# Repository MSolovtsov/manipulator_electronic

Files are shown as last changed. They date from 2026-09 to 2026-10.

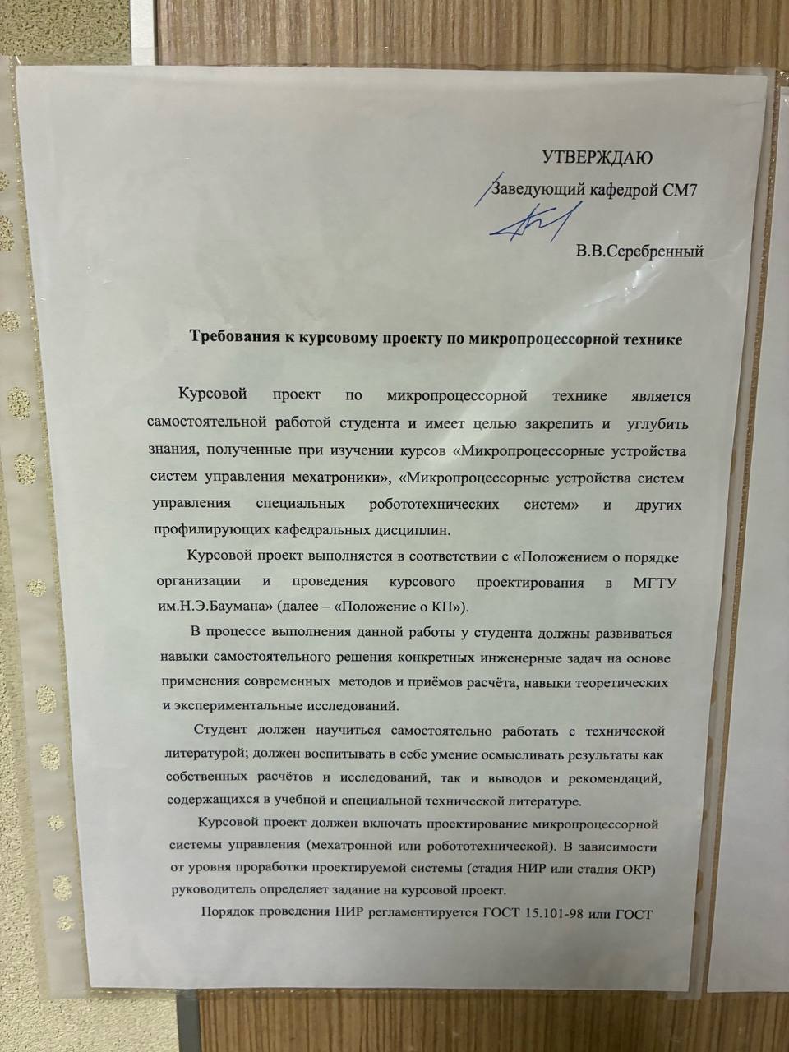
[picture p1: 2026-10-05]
docs/kp-requirements/kp-requirements-1.jpg

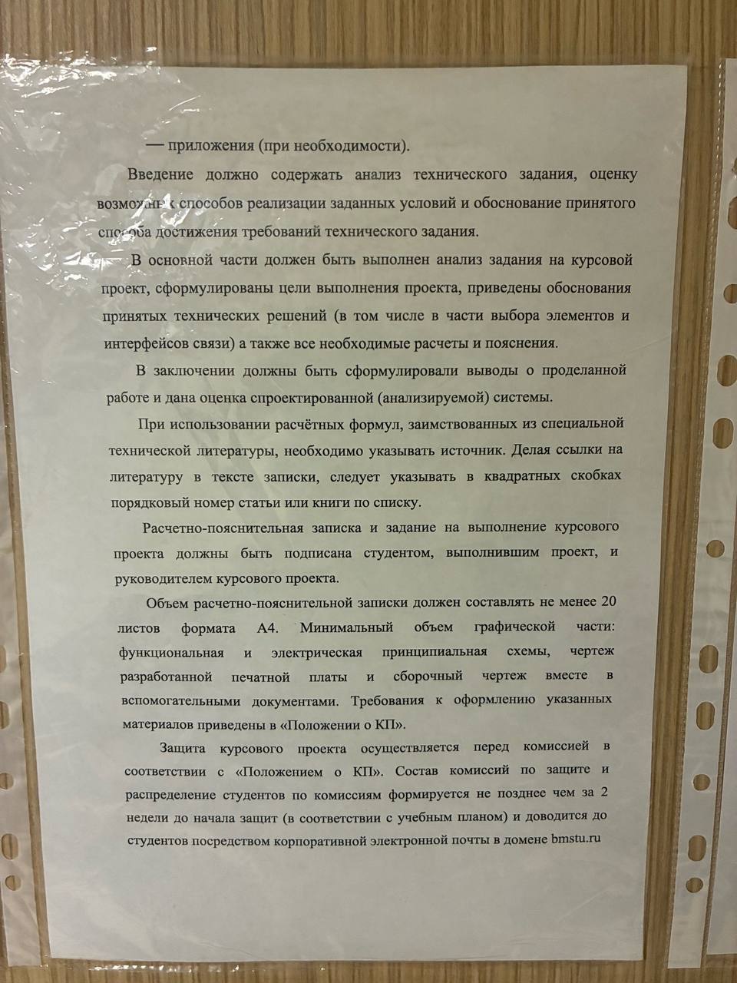
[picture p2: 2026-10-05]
docs/kp-requirements/kp-requirements-3.jpg

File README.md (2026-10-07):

# Электроника манипулятора для лабораторных работ

Подпроект «Электроника» проекта «Манипулятор для лабораторных работ». Подключён как Git submodule
к родительскому репозиторию `educational-manipulator`.

## Состав электроники

Архитектура: контроллер ESP32-S3 (связь с ПК по USB); четыре канала привода
M1…M4 в основании — коллекторные ДПТ 24 В с драйвером, реле отключения,
датчиком тока и I2C-энкодером через мультиплексор (M1 — поворот платформы,
M2…M4 — звенья через токосъёмное кольцо); съёмный схват M5 с собственной
электроникой по UART; два режима работы — полный (от ESP32) и лабораторный
(управление звеном с внешнего разъёма), переключаемые кнопкой KH; питание от
внешнего адаптера 24 В с гальванической развязкой логики от силовой части.

Конкретные компоненты, их статусы (утверждено / предложение / уточняется),
спорные пункты и цены — в базе компонентов **`bom/Component_Base.xlsx`**
(листы «Компоненты», «Модули», «Отклонено», «Сводка», «Справочники»).
Текстовые копии листов для просмотра диффов — `bom/csv/`, обновляются
скриптом `scripts/export_component_base.py`.

Не определены: число степеней свободы, грузоподъёмность, двигатели, состав и
число плат. Исходные данные — концепт на доске Miro.

| Плата | Назначение | Кол-во | Текущая ревизия |
|---|---|---|---|
| CH | Плата силовой части: развязка, драйвер, реле отключения, датчик тока, реле режима | 4 | — |
| MC | Плата микроконтроллера: ESP32-S3, мультиплексор I2C, оптореле KH, концевик M1, UART схвата, разъёмы CH | 1 | — |
| PS | Плата питания: реле шины 24 В, TVS, XL4015E, изолированный DC-DC острова, раздача +24 | 1 | — |
| LR | Плата режима ЛР: клеммы M1…M4, защита, PCF8574 и индикаторы звеньев | 1 | — |
| GR | Электроника схвата (по ТЗ на схват) | 1 | — |

Обоснование разделения, состав и связи между платами —
`docs/board-partition.md`. Плата CH проектируется после выбора двигателя
(от него зависят драйвер и реле отключения); MC, PS и LR — не ждут.

## Структура репозитория

```
electronics/
├── lib/            общие библиотеки KiCad для всех плат
│   ├── symbols/    символы (*.kicad_sym)
│   ├── footprints/ посадочные места (*.pretty/)
│   └── 3dmodels/   3D-модели компонентов (*.step, *.wrl) — только используемые в проекте
├── boards/         KiCad-проекты; один каталог = одна плата
│   └── <плата>/
│       └── release/<rev>/   замороженные выходные файлы изготовленной ревизии
├── system/         уровень системы: структурная схема, распиновка разъёмов
│   └── wiring/     схема соединений между платами, жгуты, кабели
├── calc/           расчёты: питание, токи, тепловой режим
├── bom/            база компонентов Component_Base.xlsx + csv/ для диффов
├── docs/           обоснование выбора приводов, датчиков, контроллера
└── scripts/        скрипты экспорта и проверки (export_component_base.py)
```

В репозиторий попадают исходники KiCad (`*.kicad_pro`, `*.kicad_sch`, `*.kicad_pcb`),
таблицы библиотек проекта (`sym-lib-table`, `fp-lib-table`), содержимое `lib/` и
каталоги `release/`. Резервные копии, автосохранения, локальные настройки вида
и пересоздаваемые выходные файлы (Gerber, отчёты DRC/ERC) не хранятся — см. `.gitignore`.

## Инструменты

- KiCad: **10.0**. Форматы файлов между мажорными версиями несовместимы,
  поэтому все участники работают в одной мажорной версии; она фиксируется здесь
  и не меняется в течение ревизии платы.
- `kicad-cli` — для экспорта схем, BOM и Gerber из скриптов в `scripts/`.

## Как открыть проект

Открыть `boards/<плата>/<плата>.kicad_pro` в KiCad. Библиотеки подключены через
таблицы проекта относительным путём `${KIPRJMOD}/../../lib/...`, глобальная
настройка путей не требуется.

Если KiCad сообщает об отсутствующих библиотеках:
1. проверить, что репозиторий склонирован целиком и каталог `lib/` не пуст;
2. проверить, что проект открыт из своего каталога в `boards/`, а не из копии;
3. убедиться, что версия KiCad соответствует указанной в разделе «Инструменты».

## Ревизии и выпуск

Ревизия платы записывается в поле `Rev` титульного блока схемы и выносится на
шёлкографию платы. Формат: `<код платы>-<ревизия>`, например `MC-A1`; код платы
задаётся при создании проекта платы.

На каждую ревизию, отправленную в производство, ставится Git-тег вида
`<плата>/<ревизия>`. Родительский репозиторий фиксирует коммит этого подпроекта,
поэтому по тегу родительского репозитория однозначно восстанавливается набор
ревизий всех плат конкретной версии манипулятора.

В `boards/<плата>/release/<rev>/` сохраняются выходные файлы изготовленной ревизии:
Gerber и drill, BOM, файл позиций компонентов, PDF схемы. Они соответствуют
физически существующей плате и не пересоздаются. Экспорт выполняется скриптом
из `scripts/` (команда уточняется после появления скрипта).

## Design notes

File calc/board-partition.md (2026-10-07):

# Разделение электроники на платы

Решение принято 16.09.2026. Состав и статусы компонентов каждой платы — в
`bom/Component_Base.xlsx`, колонка «Размещение» (коды плат ниже).

## Почему несколько плат, а не одна

Цепь канала привода (развязка, драйвер, реле отключения, датчик тока, реле
режима) повторяется четыре раза. Варианты:

- **Одна большая плата с четырьмя копиями цепи.** Отклонён: минимальный заказ
  у производителей — 5 шт., четыре большие платы лишние; ошибка в разводке
  канала повторяется четырёхкратно и требует перезаказа всей платы; плату
  нельзя разводить до выбора двигателя, от которого зависят драйвер и реле —
  вся электроника ждёт одного решения.
- **Одна плата канала в четырёх экземплярах + главная плата.** Принят: пятая
  плата из минимального заказа — запасная; ошибка исправляется перезаказом
  маленькой платы; отказавший канал меняется целиком; у студентов один
  понятный модуль для разбора; главную плату, питание и панель можно
  проектировать до выбора двигателя.

## Состав плат

| Код | Плата | Кол-во | Что на плате | Зависит от |
|-----|---|---|---|---|
| CH | Плата силовой части | 4 + 1 зап. | 6N137 ×2, КР293КП2Б, модуль драйвера (DRV8871 — уточняется), реле отключения (HF49FD — уточняется), модуль ACS712-20A, NRP-02 ×4, обвязка. На плате проходит граница гальванической развязки: логическая и силовая половины с зазором | двигатель (8) → драйвер (6), реле (7) |
| MC | Плата микроконтроллера | 1 | гнездо YD-ESP32-S3, TCA9548A, оптореле KH, вход концевика M1, разъём UART схвата с polyfuse на +5, разъёмы под 4 платы CH. Только логика и остров, силовых токов нет | — (можно проектировать сейчас) |
| PS | Плата питания | 1 | реле NRP-15, TVS SMCJ26A, диод катушки, модуль XL4015E, модуль VRB2405YMD-10WR3, клеммы раздачи +24 на 4 канала и схват, клемма от гнезда / предохранителя, разъёмы кнопки питания (контакт + подсветка), LED «+5P есть» и подсветки кнопки KH. Отдельно от MC из-за токов 9–10 А, реле на 30 А и тепла XL4015E | — |
| LR | Плата режима ЛР | 1 | клеммы четырёх групп M1…M4, защита у клемм (100 Ом, BAT54S, встречные диоды), PCF8574 и двухцветные светодиоды. Крепится к передней стенке корпуса | тип клемм |
| GR | Плата схвата (наименование требует уточнения) | 1 | по ТЗ на схват (контроллер, драйвер M5, датчики); разрабатывается отдельно | ТЗ схвата |

Не на платах: адаптер GST220A24-R7B и сетевой шнур (вне корпуса); гнездо
KPJX-PM-4S, кнопка питания и кнопка KH со встроенной подсветкой 24 В, индикатор +5P (панель корпуса);
держатель предохранителя (в проводе внутри корпуса); концевик M1
(основание); двигатели и AS5600 (звенья); токосъёмное кольцо.

## Связи между платами

- PS → CH ×4, MC, схват: +24 / GND_P (силовые клеммы); PS → MC: +5P/GND_P
  и +5 острова/GND_L.
- PS → панель: кнопка питания — 4 провода (XP1: контакт катушки реле + подсветка
  +24/GND_P); подсветка кнопки KH — 2 провода (XP5: +24/GND_P) кабелем напрямую
  к кнопке, минуя LR; LED «+5P есть» — 2 провода (XP4). Решение 17.09.2026:
  отдельный индикатор «+24 есть» не ставится, его роль — подсветка кнопки питания.
- MC ↔ CH (на каждый канал): IN1, IN2, RELE, CURR, SDA/SCL канала
  мультиплексора, шина KH (+5P), +5 острова, GND_L, +5P, GND_P. Способ
  соединения — кросс-плата (CH вставляются в MC как карты) или шлейфы —
  решается вместе с компоновкой корпуса.
- CH → мотор (2 провода), CH → AS5600 (4 провода), CH → LR (5 проводов:
  SCL, SDA, GND_L, IN1, IN2).
- MC → LR: I2C + питание для PCF8574.
- MC → схват: UART (RX, TX), +5, GND_L; PS → схват: +24, GND_P.

## Порядок проектирования

1. MC, PS, LR — можно начинать сейчас (все компоненты утверждены, кроме типа
   клемм LR).
2. CH — после выбора двигателя и, как следствие, драйвера и реле отключения.
3. GR — по ТЗ на схват, отдельным исполнителем.

## Отклонено

- **PD — распределительная плата платформы** (пассивная плата после
  токосъёмного кольца с разъёмами на моторы, энкодеры и схват). Решение
  Mikhail 16.09.2026: не делать; провода с кольца идут к потребителям
  напрямую.

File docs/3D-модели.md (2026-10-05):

# 3D-модели посадочных мест

Модели лежат в `lib/3dmodels/` (только используемые — CLAUDE.md), footprint ссылается на них относительным путём
`${KIPRJMOD}/../../lib/3dmodels/<файл>.step`. Ссылку, смещение и поворот задаёт `FP.set_model()` в `scripts/pcb_common.py`
(или в генераторе платы для локальных мест); библиотека `.kicad_mod` перезаписывается `scripts/gen_footprints.py`
без перегенерации плат. Формат — STEP (решение Mikhail 04.10.2026): модели попадают в STEP-экспорт платы для `mechanics`.

Смещение = положение вывода 1 нашего места в осях 3D (x как на плате, y с обратным знаком), поворот — вокруг z;
положительный rz — **по часовой стрелке** при взгляде сверху (проверено в 3D-виде KiCad 10 на CH 04.10.2026).

## Модели из библиотеки KiCad (скопированы 04.10.2026 из KiCad.app/…/3dmodels, без изменений; PinSocket 1×1, 1×3, 1×4, 1×12 — тем же днём; TerminalBlock_Phoenix_MKDS-1,5-2 — 05.10.2026)

| Footprint | Модель (STEP) | Смещение, мм | rz, ° | Высота по модели | Примечание |
|---|---|---|---|---|---|
| DIP-6_W7.62mm | DIP-6_W7.62mm | −3,81; 2,54 | 0 | 3,7 | |
| DIP-6_W7.62mm_H | DIP-6_W7.62mm | −2,54; −3,81 | −90 | 3,7 | ряд вдоль x |
| DIP-8_W7.62mm (gen_CH_pcb) | DIP-8_W7.62mm | −3,81; 3,81 | 0 | 3,7 | |
| DIP-16_W7.62mm | DIP-16_W7.62mm | −3,81; 8,89 | 0 | 3,7 | |
| R_Axial_P10.16mm | R_Axial_DIN0207_L6.3mm_D2.5mm_P10.16mm_Horizontal | −5,08; 0 | 0 | 1,25 (ось) / 2,5 | |
| R_Axial_P10.16mm_V | то же | 0; −5,08 | −90 | | |
| C_Disc_P5.00mm | C_Disc_D6.0mm_W2.5mm_P5.00mm | −2,5; 0 | 0 | 3,1 | диск ⌀6 под контур 6,4 × 2,4 |
| CP_Radial_D8.0mm_P3.50mm | CP_Radial_D8.0mm_P3.50mm | −1,75; 0 | 0 | 8,0 | модель KiCad 8 мм высотой — у выбранного конденсатора сверить |
| D_DO-35_P7.62mm | D_DO-35_SOD27_P7.62mm_Horizontal | −3,81; 0 | 0 | 2,5 | вывод 1 — катод |
| D_DO-41_P10.16mm | D_DO-41_SOD81_P10.16mm_Horizontal | −5,08; 0 | 0 | 3,2 | вывод 1 — катод |
| D_SMC | D_SMC | 0; 0 | 0 | 2,3 | |
| SOT-23 | SOT-23 | 0; 0 | 0 | 1,2 | |
| IDC-Header_2x06_P2.54mm_Vertical | IDC-Header_2x06_P2.54mm_Vertical | 6,35; 1,27 | 90 | 9,1 | паз в стенке нечётного ряда (по модели) |
| IDC-Header_2x06_P2.54mm_Vertical_D | то же | −6,35; −1,27 | −90 | 9,1 | |
| JST_XH_B2B/B4B/B5B-XH-A | JST_XH_B{n}B-XH-A_1x0{n}_P2.50mm_Vertical | x₀; 0 | 0 | 7,0 | x₀ = −(n−1)·1,25 |
| JST_XH_B4B-XH-A_R | то же | 0; −x₀ | 90 | 7,0 | вывод 1 сверху |
| JST_XH_B2B/B4B/B5B-XH-A_L | то же | 0; x₀ | −90 | 7,0 | вывод 1 снизу (после исправления 04.10.2026) |
| PinSocket_1x22_P2.54mm_Vertical | PinSocket_1x22_P2.54mm_Vertical | 0; 0 | 0 | 8,5 | |
| Module_CJMCU-9548 | PinSocket_1x12_P2.54mm_Vertical ×2 | −8,89; 13,97 и 8,89; 13,97 | 0 | 8,5 | гнёзда PBS-12 под модулем; сам модуль без модели |
| Module_DRV8871 | PinSocket_1x04_P2.54mm_Vertical | −3,81; −9,7 | −90 | 8,5 | гнездо гребёнки; клеммники POWER, MOTOR — на модуле (05.10.2026); сам модуль без модели |
| Module_ACS712 | PinSocket_1x03_P2.54mm_Vertical | −13; 2,54 | 0 | 8,5 | гнездо гребёнки; сам модуль без модели |
| TB_DG301-5.0_2P | TerminalBlock_Phoenix_MKDS-1,5-2_1x02_P5.00mm_Horizontal | 2,5; 0 | 180 | по модели Phoenix | ввод провода к −y; начало модели на площадке x = +2,5 (модель двухконтактная, выводы не различает); модель-заменитель того же шага 5,0: корпус MKDS глубже DG301 (≈9,8 против 7,6 мм в плане) — габарит и высоту DG301 сверить по чертежу Degson 200102539 |
| TB_DG301-5.0_2P_R | то же | 2,5; 0 | 180 | по модели Phoenix | вывод 1 справа (MC X4, X5); ввод провода к −y; та же оговорка |
| TB_DG301-5.0_2P_V | то же | 0; −2,5 | −90 | по модели Phoenix | ряд вдоль y, ввод провода к +x, начало модели на площадке y = +2,5 (PS X3, X5); та же оговорка |
| LED_Bicolor_5mm | LED_D5.0mm-3 | −2,54; 0 | 0 | 11,6 | у модели KiCad корпус 5,5 × 2,9 в плане — форму сверить с прибором |

## Упрощённые модели по чертежам datasheet (05.10.2026)

В библиотеке KiCad 10 моделей этих деталей нет (проверены `Relay_THT.3dshapes`, `Connector_JST.3dshapes`), готовые STEP
производителей доступны только после входа в аккаунт (SnapEDA — HF49FD, pcb-3d.com / JST — B2P-VH), для NRP-02 — нигде.
Модели построены по чертежам (корпус + выводы, без мелких деталей; источник — в таблице), начало и оси совпадают с посадочным местом:
смещение 0, поворот 0 (у _L/_V — поворот места). Заменить на STEP производителя, когда он будет.

| Footprint | Модель (STEP) | rz, ° | Габарит по модели | Источник размеров | Что оценено по чертежу (сверить) |
|---|---|---|---|---|---|
| Relay_NRP-02_1C | Relay_NCR_NRP-02_simplified | 0 | 15,5 × 10,5 × 11,5; выводы 0,6 × 0,3, 3,5 вниз | NCR NRP-02 datasheet, стр. 2 | — |
| Relay_HF49FD_1A | Relay_Hongfa_HF49FD_simplified | 0 | 20 × 5 × 12,5; выводы 0,7/0,5 × 0,3, 3,5 вниз | Hongfa HF49FD datasheet, стр. 2 | с какой стороны ряда корпус выступает на 4,1 мм |
| JST_VH_B2P-VH | JST_VH_B2P-VH_simplified | 0 | 7,86 × 8,5, выводы 1,14 до 10,9 над платой и 3,7 вниз | JST eVH, Header (Standard type), Top entry; вывод 1,14 — pcb-3d.com | ряд в 3,5 мм от стенки, стенка 1,4 × 9,1, основание 3,4 |
| JST_VH_B2P-VH_L, _V | то же | −90 / 90 | | | |
| Relay_NRP-15_1C | Relay_NCR_NRP-15_simplified | 0 | 27,5 × 32 × 20, **только корпус** | габарит NCR (как контур места) | выводы не показаны — нет чертежа NCR NRP-15 |
| DCDC_Mornsun_YMD_25.4x25.4 | DCDC_KCUT_URB2405YMD-10WR3_simplified | 0 | 24,5 × 25,4 × 11,0; выводы ⌀1,0, 4,1 ниже корпуса | корпус — фото продавца купленного K-CUT URB2405YMD-10WR3 (05.10.2026); выводы и их места — Mornsun VRA(B)_YMD-10WR3, rev. 2026.03.03-B/8, стр. 6 | направление 24,5 (поперёк рядов выводов) — по фото; длина выводов K-CUT |
| L_Toroid_D20_P10.16mm | L_Toroid_Talema_DPO-3.0-22_flat_simplified | 0 | ⌀14 × 8, кольцо лежит (решение Mikhail 05.10.2026); выводы ⌀0,5, 3,5 вниз | Talema DP Series: DPO-3.0-22 — O.D. 14 × Ht 8, провод 0,5 | внутренний диаметр не указан — сплошной габарит; вылет выводов под платой |
| Fuse_PTC_Radial_P5.08mm | Fuse_PTC_Bourns_MF-R110_simplified | 0 | 8,9 × 3,0 × 14,0; выводы ⌀0,51, 3,5 вниз | Bourns MF-R, rev. Z 06/13, Product Dimensions, Style 1 (MF-R110: A 8,9, B 14,0, E 3,0, C 5,1 ± 0,7) | высота посадки над платой (E-083 — MF-R110, утверждено 05.10.2026) |

## Без модели — требуется исходная информация

| Footprint | Что нужно | Где взять |
|---|---|---|
| Module_DRV8871, Module_ACS712, Module_CJMCU-9548 (сам модуль над гнёздами) | габариты и высота купленных модулей | замер / фото с линейкой |
| Module_XL4015E_zone | модель не делается (решение Mikhail 05.10.2026); габарит 54 × 24 × 15 — на F.Fab и в высоте места | — |
| TermGroup_5x_Banana4 | тип клемм не определён (E-051 — «комбинированные клеммы») | datasheet выбранной клеммы |

Упрощённые модели-габариты (параллелепипед/цилиндр по известным размерам) делаются одной партией, когда соберутся
высоты; придумывать высоту «на глаз» нельзя (CLAUDE.md).

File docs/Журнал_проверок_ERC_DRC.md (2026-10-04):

# Журнал проверок ERC / DRC

Запись добавляется после каждого прогона ERC (схема) или DRC (плата) в KiCad 10.
Хеш файла — `git hash-object boards/<КОД>/<КОД>.kicad_sch` (или `.kicad_pcb`),
первые 8 знаков; по нему видно, к какой именно версии файла относится проверка.
Отчёты `*.rpt` в репозиторий не попадают — сюда заносится только итог.
Плата не генерируется по схеме, у которой нет записи ERC с актуальным хешем.

| Дата | Плата | Файл | Хеш | Проверка | Ошибок | Предупреждений | Кто | Примечание |
|---|---|---|-----|---|---|---|-----|---|
| | | | | | | | | |

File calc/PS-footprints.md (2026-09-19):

# Плата PS — посадочные места и правила трассировки

Плата собирается генератором `scripts/gen_PS_pcb.py` (файл `boards/PS/PS.kicad_pcb`,
библиотека `lib/footprints/manipulator.pretty`), проверяется `scripts/check_pcb.py`.
Здесь — откуда взяты размеры и что нужно проверить руками до заказа.

## Технология (Резонит, по образцу чертежа кафедры)

| Параметр | Значение |
|---|---|
| Слои | 2 (F.Cu, B.Cu) |
| Материал | FR-4, толщина 1,6 мм ± 10 % |
| Медь | фольга 18 мкм (в стеке 0,0175), финиш HAL бессвинцовый |
| Маска | PSR-4000 H85 или аналог, 0,01 мм |
| Класс точности | 3 по ГОСТ 23751-86 |
| Зазор / проводник, минимум завода | 0,3 / 0,3 мм (в проекте принято 0,5 / 0,5) |
| Шаг сетки | 1 мм (компоненты — по сетке 0,5 мм там, где шаг выводов дюймовый) |
| Крепёж платы | 4 × М3 (⌀3,2): три в углах и одно на правом краю между XT6 и XP2; плата 120 × 100 мм |

Ширины проводников (ток при подъёме ~20 °C на меди 35 мкм после металлизации):

| Цепь | Ток | Ширина | Слой |
|---|---|---|---|
| +24V_IN: XT1 → VD1 → K1 COM; K1 NO → зона | до 9,2 А | 6 мм | F.Cu |
| +24V раздача на XT2…XT6, U1, U2, подсветку | ≤ 3 А на отвод | зона F.Cu; отводы 1,5–3 мм | F.Cu |
| GND_P | — | зона B.Cu (термобарьеры 1,0 мм, зазор 0,6) | B.Cu |
| +5P (U1 → L1 → C1/C2 → XP2) | ≤ 2 А | 2 мм | F.Cu |
| Остров +5V_L / GND_L (U2 → XP3) | ≤ 2 А | 1,5 мм | F.Cu / B.Cu |
| Катушка K1, LED, подсветка | < 0,1 А | 0,8 мм | F.Cu / B.Cu |

Гальванический остров: правая половина U2 и XP3 лежат внутри зоны +24V, поэтому под ними на обеих
сторонах стоит запрет заливки (keepout copperpour) 90…108 × 22…58 мм; расстояние от меди острова до
любой меди силовой стороны ≥ 2 мм (проверяется скриптом). Граница показана штрих-пунктиром на шелкографии.
Под модулем U1 — запретная зона для меди на обоих слоях (открытые пайки на нижней стороне модуля).

## Посадочные места — источники размеров

| Footprint | Компонент | Источник | Ключевые размеры | Проверить |
|---|---|---|---|---|
| `TB_DG301-5.0_2P`, `_V` | XT1…XT6, Degson DG301-5.0-02P-12 (E-017) | чертёж Degson 200102539 rev 03 (2025) | шаг 5,0; вывод ⌀1,0 → отв. 1,3, площадка 2,4; корпус 10,0 × 7,6 × 10; ряд выводов в 4,5 мм от стороны ввода провода | — |
| `Relay_NRP-15_1C` | K1, NCR NRP-15-C-24D (E-013) | datasheet NCR NRP15 (ncr.hk, «PCB layout» — вид снизу) | контакты 1,2 × 1,2 → отв. 2,1, площадка 3,5; катушка 0,8 × 0,8 → отв. 1,3; корпус 27,5 × 32; 6 отверстий (второе COM — для 6-выводного варианта) | **ориентация**: вид снизу зеркалирован в вид сверху по моему прочтению чертежа; перед пайкой прозвонить обесточенное реле: COM–NC замкнуты, COM–NO разомкнуты — и сверить с шёлкографией |
| `DCDC_Mornsun_YMD_25.4x25.4` | U2, VRB2405YMD-10WR3 (E-010) | datasheet Mornsun VRA(B)_YMD-10WR3 2026.03, стр. 6 «Top view (PCB layout)» | сетка 2,54; вывод ⌀1,0 → отв. 1,4 (datasheet 1,5), площадка 2,4; 1 Ctrl, 2 GND, 3 Vin слева; 6 0V, (5 нет), 4 +Vo справа | — |
| `JST_XH_B2B-XH-A`, `B4B` | XP4, XP5, XP1 (E-018, E-092) | библиотека KiCad (JST eXH.pdf — скан, размеры с чертежа не снимал) | шаг 2,5; отв. 1,0, площадка 1,8; корпус (n−1)·2,5 + 4,9 × 5,75 | сверить корпус и положение ряда выводов с чертежом JST |
| `JST_VH_B2P-VH_V` | XP2, XP3 (E-019) | библиотека KiCad (JST eVH.pdf) | шаг 3,96; отв. 1,7, площадка 2,8; корпус ≈ 9,96 × 7,0 | сверить с чертежом JST |
| `D_SMC` | VD1, SMCJ26A (E-004) | стандарт DO-214AB | площадки 2,9 × 3,0 в ±3,55 | — |
| `D_DO-41_P10.16mm` | VD2, 1N4007 (E-015) | стандарт | шаг 10,16; отв. 1,1 | — |
| `R_Axial_P10.16mm_V` | R2 (E-009) | стандарт 0,25 Вт | шаг 10,16; отв. 0,9; вывод 1 снизу | — |
| `CP_Radial_D8.0mm_P3.50mm` | C1 (E-093) | стандарт ⌀8 | шаг 3,5; отв. 1,0; «+» — вывод 1 | диаметр купленного конденсатора ≤ 8,5 мм |
| `C_Disc_P5.00mm` | C2 (E-094) | стандарт | шаг 5,0; отв. 0,9 | — |
| `L_Toroid_D20_P10.16mm` | L1, Talema DPO-3.0-22 (E-012) | TME (⌀14 × 8), каталог Talema DP (20 × 8) | выводы 0,5 мм гибкие → отв. 1,1, шаг 10,16; courtyard ⌀20 | — |
| `Module_XL4015E_zone` | U1 (E-007) | решение Mikhail 17.09: зона с пазами, подключение проводами | зона 60 × 32; 4 паза 3,2 × 10 под 45° в углах 44 × 20; пятаки IN+/IN−/OUT+/OUT− отв. 1,5 | после покупки модуля убедиться, что его отверстия попадают в пазы |
| `MountingHole_3.2mm_M3` | H1…H4 | — | ⌀3,2 без металлизации | — |

## Порядок работы в KiCad 10

1. Открыть `boards/PS/PS.kicad_pro` → PCB Editor. Файл платы записан в формате KiCad 9; при
   первом сохранении KiCad 10 перепишет его в свой формат — это нормально.
2. Нажать **B** (заполнить зоны): зоны +24V (F.Cu) и GND_P (B.Cu) в файле не залиты.
3. Tools → Update PCB from Schematic (F8). Ожидаются только переименования безымянных цепей
   (`Net-(…)`), footprint'ы и их привязка к символам заданы по UUID.
4. Inspect → DRC. Правила и классы цепей — в `PS.kicad_pro` (Default 0,5/0,8; Power24 6,0;
   Power5 2,0; Island 1,5, зазор 1,0).
5. Замечания — в чат; правки вносятся в `gen_PS_pcb.py`, не в файле платы вручную.

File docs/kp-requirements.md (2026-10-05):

# Требования к курсовому проекту по микропроцессорной технике

Расшифровка документа, вывешенного на кафедре СМ7. Исходные фотографии —
`docs/kp-requirements/kp-requirements-1.jpg … -3.jpg`. При расхождении верен
оригинал; текст набран с фотографий и мог воспроизвести опечатки исходника.

**УТВЕРЖДАЮ.** Заведующий кафедрой СМ7, В.В. Серебренный.

## Назначение

Курсовой проект по микропроцессорной технике является самостоятельной работой
студента и имеет целью закрепить и углубить знания, полученные при изучении
курсов «Микропроцессорные устройства систем управления мехатроники»,
«Микропроцессорные устройства систем управления специальных робототехнических
систем» и других профилирующих кафедральных дисциплин.

Курсовой проект выполняется в соответствии с «Положением о порядке организации
и проведения курсового проектирования в МГТУ им. Н.Э. Баумана» (далее —
«Положение о КП»).

В процессе выполнения данной работы у студента должны развиваться навыки
самостоятельного решения конкретных инженерных задач на основе применения
современных методов и приёмов расчёта, навыки теоретических и экспериментальные
исследований.

Студент должен научиться самостоятельно работать с технической литературой;
должен воспитывать в себе умение осмысливать результаты как собственных
расчётов и исследований, так и выводов и рекомендаций, содержащихся в учебной
и специальной технической литературе.

## Содержание проекта

Курсовой проект должен включать проектирование микропроцессорной системы
управления (мехатронной или робототехнической). В зависимости от уровня
проработки проектируемой системы (стадия НИР или стадия ОКР) руководитель
определяет задание на курсовой проект.

Порядок проведения НИР регламентируется ГОСТ 15.101-98 или ГОСТ РВ 15.105-2001.
Конкретный состав этапов и характер выполняемых в их рамках работ определяются
спецификой НИР. Графические материалы проекта должны соответствовать уровню
проектирования макетов. Типовые задания для выполнения курсовых проектов:

- конструктивная проработка микропроцессорной системы на основе однокристальной
  микро ЭВМ;
- разработка устройств сопряжения однокристальной микро ЭВМ с объектом
  управления.

Основные этапы ОКР определяются ГОСТ 15.201-2000 или ГОСТ РВ 15.203-2001 и
должны включать:

- разработку упрощённой функциональной схемы системы;
- выбор элементов (запоминающих устройств, устройств ввода-вывода,
  вспомогательных устройств) и разработку электрической принципиальной схемы
  системы;
- разработку печатной платы микропроцессорной системы.

Курсовой проект должен включать в себя расчётно-пояснительную записку и
графическую часть.

## Состав расчётно-пояснительной записки

Как обязательные компоненты в расчётно-пояснительную записку должны быть
включены:

- титульный лист (образец в Приложении 3 к «Положению о КП»);
- задание на курсовой проект (образец в Приложении 5 к «Положению о КП»);
- календарный план выполнения курсового проекта (образец в Приложении 7
  к «Положению о КП»);
- оглавление;
- список обозначений и сокращений (при необходимости);
- введение;
- основная часть;
- заключение;
- список использованных источников;
- приложения (при необходимости).

Введение должно содержать анализ технического задания, оценку возможных
способов реализации заданных условий и обоснование принятого способа
достижения требований технического задания.

В основной части должен быть выполнен анализ задания на курсовой проект,
сформулированы цели выполнения проекта, приведены обоснования принятых
технических решений (в том числе в части выбора элементов и интерфейсов связи),
а также все необходимые расчёты и пояснения.

В заключении должны быть сформулированы выводы о проделанной работе и дана
оценка спроектированной (анализируемой) системы.

## Источники и подписи

При использовании расчётных формул, заимствованных из специальной технической
литературы, необходимо указывать источник. Делая ссылки на литературу в тексте
записки, следует указывать в квадратных скобках порядковый номер статьи или
книги по списку.

Расчётно-пояснительная записка и задание на выполнение курсового проекта должны
быть подписаны студентом, выполнившим проект, и руководителем курсового
проекта.

## Объём

Объём расчётно-пояснительной записки должен составлять не менее 20 листов
формата А4.

Минимальный объём графической части: функциональная и электрическая
принципиальная схемы, чертёж разработанной печатной платы и сборочный чертёж
вместе с вспомогательными документами. Требования к оформлению указанных
материалов приведены в «Положении о КП».

## Защита

Защита курсового проекта осуществляется перед комиссией в соответствии с
«Положением о КП». Состав комиссий по защите и распределение студентов по
комиссиям формируется не позднее чем за 2 недели до начала защит
(в соответствии с учебным планом) и доводится до студентов посредством
корпоративной электронной почты в домене bmstu.ru.

## Решения руководителя по данному проекту

- Стадия — **ОКР**, этапы по ГОСТ 15.201-2000.
- В графическую часть идут **все платы** проекта.
- Вспомогательный документ к сборочному чертежу — **спецификация на каждую
  плату** отдельно.

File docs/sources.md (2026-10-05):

# Список использованных источников

Единый сквозной список для подпроекта `electronics`. На него ссылаются расчёты
в `calc/`, обоснования в `docs/` и пояснения в генераторах схем и плат.

**Правила ведения**

- Нумерация сквозная и задним числом не меняется: новый источник дописывается
  в конец списка. Освободившийся номер не переиспользуется.
- Ссылка в тексте и в комментарии скрипта — `[N]`, где N — номер из этого
  списка. Для формулы указывается ещё и место: `[4, с. 112]`, `[7, табл. 3]`.
- Выходные данные приводятся полностью. Если чего-то не хватает — строка
  остаётся с пометкой «уточнить», и источник не используется в записке, пока
  пометка не снята.
- Строки с пометкой «уточнить» перед сдачей записки должны быть закрыты либо
  удалены вместе со ссылками на них.

**Формат строки**

Книга — автор, название, издание, город, издательство, год, страницы.
Стандарт — обозначение, название, год введения.
Документация компонента — производитель, обозначение документа, название,
ревизия, год.

---

1. Требования к курсовому проекту по микропроцессорной технике : утв.
   заведующим кафедрой СМ7 МГТУ им. Н.Э. Баумана В.В. Серебренным. — Расшифровка
   и фотографии: `docs/kp-requirements.md`. — Дата утверждения: уточнить.
2. Положение о порядке организации и проведения курсового проектирования
   в МГТУ им. Н.Э. Баумана. — Выходные данные: уточнить.
3. Хоровиц П., Хилл У. Искусство схемотехники. Теория и практика. — 2022. —
   Город, издательство, число страниц: уточнить.
4. ГОСТ 2.104. Единая система конструкторской документации. Основные надписи. —
   Год введения: уточнить.
5. ГОСТ 2.304. Единая система конструкторской документации. Шрифты чертёжные. —
   Год введения: уточнить.
6. ГОСТ 2.702. Единая система конструкторской документации. Правила выполнения
   электрических схем. — Год введения: уточнить.
7. ГОСТ 2.710. Единая система конструкторской документации. Обозначения
   буквенно-цифровые в электрических схемах. — Год введения: уточнить.
8. ГОСТ 15.201-2000. Система разработки и постановки продукции на производство.
   Продукция производственно-технического назначения. Порядок разработки
   и постановки продукции на производство.
9. Allegro MicroSystems. ACS712. Fully Integrated, Hall-Effect-Based Linear
   Current Sensor IC : datasheet. — Обозначение документа и ревизия: уточнить.
10. Texas Instruments. DRV8871. 3.6-A Brushed DC Motor Driver with Internal
    Current Sense : datasheet. — Обозначение документа и ревизия: уточнить.
11. Нормы технологических возможностей изготовления печатных плат (базовый
    уровень) : ООО «Резонит». — Редакция и дата обращения: уточнить.

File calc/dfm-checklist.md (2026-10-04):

# Контроль печатной платы на дефекты — шесть этапов и журнал DFM

САПР проверяет математику (соединения, зазоры в модели), завод проверяет физику (биение
сверла, подтрав меди, разрешение трафарета шелкографии, реальный стек материалов).
«DRC — No errors» означает только то, что сошлась модель. Поэтому контроль разделён на
шесть этапов: каждый ловит свой класс дефектов и слеп к остальным, пропуск этапа
другими не компенсируется.

Нормы — словарь `DFM` в `scripts/pcb_common.py`; машинная часть проверок — блоки 7–9
`scripts/check_pcb.py`. Этапы 0 и 6 выполняет Mikhail, они не автоматизируются.

## Этап 0 — данные завода (до разводки)

Запросить и зафиксировать до того, как начата компоновка:

| Что | Значение | Источник, дата |
|---|---|---|
| Класс точности | требует уточнения | |
| Доступные стеки (core/prepreg) | требует уточнения | |
| Толщина фольги | 18 мкм (принято) | Резонит, базовый уровень |
| Минимальные проводник / зазор | 0,125 / 0,125 | Резонит, базовый уровень |
| Минимальное отверстие PTH / NPTH | 0,3 / 0,5 | Резонит, базовый уровень |
| Минимальный поясок | 0,2 | Резонит, базовый уровень |
| Шелкография: линия / шрифт | 0,15 / 1,0 | Резонит, базовый уровень |
| Зазор шелкографии до маски | требует уточнения (принято 0,2) | |
| Требования к панелизации | требует уточнения | |

Без этих данных остальные этапы сверяются не с заводом, а с допущениями.

## Этап 1 — электрика (математика)

`python3 scripts/check_sch_pcb.py <КОД>` и `python3 scripts/check_pcb.py <КОД>` (блоки 1–6),
затем DRC в KiCad. Ловит обрывы, короткие замыкания, расхождение со схемой, нарушение
классов цепей. Не ловит ничего физического.

## Этап 2 — механика

Контур, габариты, крепёж, посадка в корпус, стыковка разъёмов «контакт в контакт»,
courtyard, медь до края. Блок 8 `check_pcb.py`.

Типовой дефект: медь подходит к крепёжному NPTH вплотную. В САПР зазор есть, но сверло
имеет биение и съедает его — в отверстие смотрит голый торец меди. Металлический винт
замыкает его на корпус, а стойка соединяет цепи на F.Cu и B.Cu. Норма: медь до крепёжного
отверстия ≥ 1,0 мм, вырез заливки ⌀8 мм на обеих сторонах (`hole_keepouts()`), вокруг
одного винта — не более одной цепи.

## Этап 3 — геометрия меди

Углы изломов, острые стыки меди, узкие перешейки и тонкие «иголки», поясок с учётом
биения сверла. Блок 7 `check_pcb.py`.

Типовой дефект: острый угол — кислотная ловушка: раствор застревает, медь перетравливается,
появляется риск обрыва. Прямой угол даёт локальное уширение проводника и ступеньку
импеданса. Норма: только 45°; `Router` ортогональный, поэтому в конце генератора —
`chamfer_tracks()`.

## Этап 4 — сборка

Шелкография против площадок и окон маски, полярность и первый вывод, читаемость
позиционных обозначений, доступ к разъёмам и подстройке, панелизация. Блок 9 `check_pcb.py`.

Типовой дефект: надпись заходит на контактную площадку. Завод не «немного потерпит» —
он вырежет попавший кусок рисунка, чтобы краска не попала на площадку, и сделает это
молча. Монтажник получит нечитаемую маркировку. Норма: ≥ 0,2 мм до края площадки
и окна маски, поверх площадки — запрещено.

## Этап 5 — физика материалов

Реальный стек, толщина меди, трапецеидальное сечение проводника после травления, нагрев
и падение напряжения. Контролируемого импеданса в проекте нет (I2C ~100 кГц, ШИМ приводов,
питание) — требований по импедансу не изобретать. Что применимо: фактическое сечение
проводника меньше нарисованного, поэтому ширины питания держать с запасом, а не впритык.

Типовой дефект для плат с быстрыми линиями: ширина посчитана в калькуляторе САПР на
условном Er, а завод собирает плату из своих стандартных комбинаций материалов — расчётные
50 Ом превращаются в 42 Ом.

## Этап 6 — DFM-анализ Gerber (до заказа)

Экспортировать из KiCad Gerber и файл сверловки, прогнать через DFM-сервис завода
и разобрать отчёт **построчно**: каждая строка либо исправляется, либо получает письменное
обоснование отказа. Результат — в журнал ниже.

### Журнал разбора

| Дата | Плата | Ревизия | Сервис | Строка отчёта | Решение | Кем |
|---|---|---|---|---|---|---|
| | | | | | | |

## Как не попадать в эти дефекты заранее

1. Нормы завода держать одним словарём в коде, а не рассыпанными по генераторам;
   DFM-нормы лежат там же, где нормы DRC.
2. Крепёж, зоны отчуждения вокруг него и границу развязки закладывать на этапе компоновки,
   до трассировки: переставить отверстие в конце разводки дороже всего.
3. Геометрию ограничивать инструментом, а не дисциплиной: генератор, который сам скашивает
   углы, надёжнее правила «не ставить прямых углов».
4. Шелкографию генерировать после площадок и проверять числами, а не глазами по превью.
5. Запас держать относительно нормы завода, а не равняться на минимум: принятые в проекте
   0,5 вместо 0,3 — это и есть защита от биения сверла и подтрава.
6. Любой параметр, взятый по умолчанию (Er, стек, толщина меди), помечать как допущение:
   именно такие умолчания и расходятся с производством.

## Этап 4а — компоновка как источник дефектов разводки

Отдельная строка, потому что это причина, а не следствие: хаос в трассировке закладывается
в расстановке. Порядок работы и нормы — `CLAUDE.md`, «Порядок расстановки — узлами, а не поштучно»;
машинная часть — блоки 10–12 `check_pcb.py`.

Коротко: конструктив по чертежу и в `FIXED`; доступ паяльником и феном; разбиение на функциональные
узлы `UNITS`, каждый компонент ровно в одном; узлы ставятся по числу связей, первым — самый связанный;
коридоры межузловых трасс в `CHANNELS`; развязка вплотную к выводу питания; интерфейсная микросхема
и защита — у разъёма; шумное и чувствительное по разным углам.

Признак провала компоновки: переходов на цепь больше `DFM["via_per_net"]` либо поворотов на дорожку
больше `DFM["bends_max"]`. Численная мера — HPWL, печатается чекером; после перекомпоновки сравнивать.

## Текущее состояние (на 2026-10-03, платы ещё не перегенерированы)

Проверки добавлены, генераторы правлены, `.kicad_pcb` пока старые. Цифры ниже — из генераторов,
не из файлов плат. После перегенерации повторить все блоки и обновить таблицы.

| Плата | Углы (7) | Крепёж (8) | Шелкография (9) | Компоновка (10) | Разводка (11) |
|---|---|---|---|---|---|
| PS | чисто после `chamfer_tracks()` | чисто после `hole_keepouts()` | 5 наложений на площадки | узел «понижающий DC-DC +5P» растащен: U1 в 50 мм от центра узла | переходов 0, меди 431 мм |
| MC | чисто | чисто | 5 наложений, 6 на переходы | узлы «питание логики» / «вход X1 и делитель» / «вход IO48» перемешаны | переходов 132, 10 цепей с > 4 переходами, меди 3836 мм |
| CH | чисто | чисто | 0 наложений, 6 на переходы | узел «драйвер и выходы на двигатель» растащен: U4 в 26 мм | переходов 71, 3 цепи с > 4 переходами, меди 1948 мм |
| LR | платы нет | платы нет | платы нет | платы нет | платы нет |

Длины связей (HPWL) на момент правки: PS 675 мм (9 цепей, в среднем 75), MC 3755 мм (42 цепи, 89),
CH 1677 мм (32 цепи, 52). Худшие цепи MC: `GND_L` 193, `+5V_L` 182, `3V3` 152, `M4_IN2` 147 мм.

### Открытые последствия ужесточения норм

- Отступ меди от крепёжного отверстия поднят с 0,2 до 1,0 мм, и трассировщик MC перестал проводить
  цепь `3V3` (5 выводов: U1.1, R1.1, R2.1, R3.1, X10.1). На прежней норме плата разводилась целиком
  (137 переходов, 0 отказов). Это не регресс чекера, а честный результат: коридор у правого края
  между крепёжными отверстиями (116,4), (116,72), (116,78) при норме 1,0 мм закрывается.
  Лечится перекомпоновкой — перенести X10 или сдвинуть крепёж, — а не возвратом к 0,2 мм.
- Стратегия слоёв `"plane"` (сигналы по F.Cu, B.Cu под землю) реализована, но умолчанием не стала.
  Замер на нынешней расстановке: MC 132 → 82 перехода, но отказов 5 → 9; CH 71 → 27 переходов,
  отказов 0 → 19. Вывод: экономия переходов упирается в компоновку. Переключать после перекомпоновки.

### Что устраняется при следующей перегенерации плат

1. Наложения шелкографии (перенос надписей и обозначений).
2. Цепь `3V3` на MC — перенос X10 или крепежа.
3. Узел «понижающий DC-DC +5P» на PS — собрать U1 с L1/C1/C2 в один компактный узел.
4. Узел «драйвер и выходы на двигатель» на CH — подтянуть U4 к X4/X5.
5. Перемешанные входные узлы на MC по левому краю.
6. Назначение выводов ESP32 каналам: цепи `M4_*` идут от X9 (x = 106,7) к дальнему гнезду XS1
   (x = 34) мимо ближнего XS2 (x = 59,4) — 147 мм на двухвыводную цепь. Требует проверки
   ограничений ESP32 (strapping-выводы, только-входы, АЦП) перед правкой схемы.

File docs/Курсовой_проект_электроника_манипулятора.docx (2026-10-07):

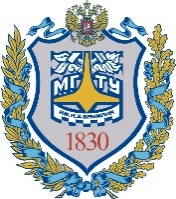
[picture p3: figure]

| Министерство науки и высшего образования Российской Федерации Федеральное государственное автономное образовательное учреждение высшего образования «Московский государственный технический университет имени Н.Э. Баумана (национальный исследовательский университет)» (МГТУ им. Н.Э. Баумана)

ФАКУЛЬТЕТ | «Специальное машиностроение»
КАФЕДРА | «Робототехнические системы и мехатроника»

КУРСОВОЙ ПРОЕКТ

ПО ДИСЦИПЛИНЕ

МИКРОПРОЦЕССОРНЫЕ УСТРОЙСТВА

СИСТЕМ УПРАВЛЕНИЯ СРТС

НА ТЕМУ:

Студент | СМ7-21М
| (группа) | | (подпись, дата) | | (И.О. Фамилия)
Руководитель курсового проекта
| | | (подпись, дата) | | (И.О. Фамилия)
Консультант
| | | (подпись, дата) | | (И.О. Фамилия)

2026 г.

Министерство науки и высшего образования Российской Федерации

Федеральное государственное автономное образовательное учреждение

высшего образования

«Московский государственный технический университет имени Н.Э. Баумана

(национальный исследовательский университет)»

(МГТУ им. Н.Э. Баумана)

Утверждаю
Заведующий кафедрой
| | | (индекс)
| | (И.О. Фамилия)
(подпись)
| | (дата)

ЗАДАНИЕ

на выполнение курсового проекта

по дисциплине | | Микропроцессорные устройства систем управления СРТС
Студент группы | | Соловцов Михаил Андреевич
| | (Фамилия, имя, отчество)
Тема курсового проекта

Направленность КР (учебная, исследовательская, практическая, производственная, др.)

учебная
Источник тематики (кафедра, предприятие, НИР) | | | | кафедра
Задание

Разработать электронику системы управления приводами учебного манипулятора:

четыре канала коллекторных ДПТ 24 В с обратной связью по току и положению,

микроконтроллерное управление со связью с ПК, режим лабораторных работ

с внешним управлением звеном, узел питания с гальванической развязкой логики.

Выбрать и рассчитать элементы, разработать функциональную и принципиальные

схемы, печатные платы узлов.
Оформление курсового проекта:

Расчетно-пояснительная записка (Отчет по КР) на _43_ листах формата А4.

Дата выдачи задания « ___ » ____________ 20__ г.

Руководитель курсового проекта
| | (подпись, дата) | | (И.О. Фамилия)
Студент
| | (подпись, дата) | | (И.О. Фамилия)

Примечание: Задание оформляется в двух экземплярах: один выдается студенту, второй хранится на кафедре.

Министерство науки и высшего образования Российской Федерации

Федеральное государственное автономное образовательное учреждение

высшего образования

«Московский государственный технический университет имени Н.Э. Баумана

(национальный исследовательский университет)»

(МГТУ им. Н.Э. Баумана)

КАЛЕНДАРНЫЙ ПЛАН

на выполнение курсового проекта

по дисциплине | Микропроцессорные устройства систем управления СРТС
Студент группы | Соловцов Михаил Андреевич
| (Фамилия, имя, отчество)
Тема курсового проекта

№ п/п | Наименование этапов выпускной квалификационной работы | Сроки выполнения этапов | | Отметка о выполнении
| | план | факт | Руководитель КП | Куратор
1. | Задание на выполнение курсовогопроекта
2. | 1 модуль | ____________ Планируемаядата
3. | 2 модуль | ____________ Планируемаядата
4. | Оформление РПЗ (Отчета) | ____________ Планируемаядата
5. | Подготовка доклада и презентации (при необходимости) | ____________ Планируемаядата
6. | Защита курсового проекта | ____________ Планируемая дата

Студент __________________________ Руководитель проекта _________________________

(подпись, дата) (подпись, дата)

# Содержание

# Введение

Учебный манипулятор — четырёхзвенный робот со съёмным схватом, предназначенный для лабораторных работ по курсам мехатроники и робототехники. Робот разрабатывался на кафедре в нескольких предыдущих курсовых проектах (механика звеньев, привод четвёртого звена), однако в эксплуатацию не вводился: отсутствовала работоспособная электроника, связывающая приводы, датчики и управляющую ЭВМ. Цель настоящего курсового проекта — разработать электронику системы управления приводами манипулятора, доведя робот до работоспособного состояния в рамках существующей документации по механике.

Структурная схема привода одного звена, принятая за основу, приведена на рисунке 1.

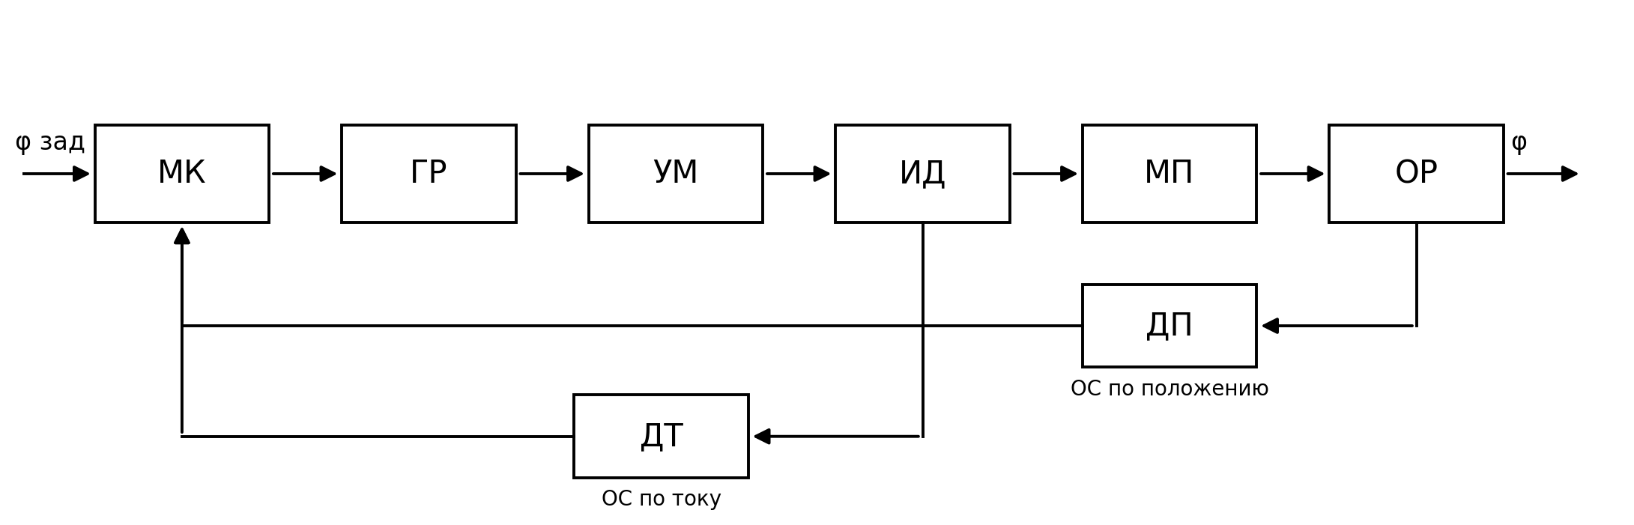
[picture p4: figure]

Рисунок 1. Структурная схема привода звена

МК — микроконтроллер, выполняющий корректирующее устройство и формирующий сигналы ШИМ; ГР — гальваническая развязка сигналов управления; УМ — усилитель мощности (драйвер ДПТ); ИД — исполнительный двигатель постоянного тока; МП — механическая передача (редуктор и ремённые передачи); ОР — объект регулирования (звено манипулятора с грузом); ДП — датчик положения; ДТ — датчик тока якоря. Обратная связь по положению обеспечивает отработку заданного угла, обратная связь по току — контроль усилия и защиту двигателя.

В отличие от предыдущих проектов, где проектировалась плата управления одним приводом, здесь решается задача системного уровня: четыре канала привода, съёмный схват со своей электроникой, два режима работы (управление от контроллера стенда и управление звеном с внешнего разъёма студента), узел питания и гальваническая развязка логической части от силовой. Для реализации системы необходимо выбрать и рассчитать следующие функциональные элементы:

- двигатели звеньев и драйверы двигателей;
- элементы гальванической развязки сигналов управления;
- датчики тока и углового положения;
- микроконтроллер и его периферию (мультиплексор I2C, расширитель портов);
- источники питания силовой и логической частей, элементы защиты;
- разделение электроники на печатные платы и их топологию.

Проектирование ведётся в KiCad 10; результаты работы (схемы, платы, база компонентов, расчёты) хранятся в Git-репозитории подпроекта «Электроника» проекта «Учебный манипулятор» [1].

# 1 Техническое задание

В ходе курсового проекта необходимо разработать электронику системы управления приводами учебного манипулятора: четырьмя коллекторными двигателями постоянного тока звеньев M1…M4 и съёмным схватом M5.

Исходные данные по механике приняты по расчётно-пояснительной записке привода четвёртого звена [19] и энергетическому расчёту приводов [2]; массы и длины звеньев приведены в таблице 1, требования к приводам — в таблице 2.

Таблица 1.

Массы и длины звеньев

Элемент | Масса m, кг | Длина l, мм
Звено 2 | 3,5 | 540
Звено 3 | 1,5 | 400
Звено 4 | 0,74 | 270
Груз | 0,5 | —

Таблица 2.

Требования технического задания к приводам звеньев

Параметр | Обозначение | Значение
Тип двигателей | — | постоянного тока, коллекторные
Напряжение питания приводов, В | U | 24
Угол поворота звена, не более | φ | 360°
Угловая скорость звена, рад/с | φ′ | 0,4
Угловое ускорение звена, рад/с² | φ″ | 1
Статическая ошибка по положению, не более | δ | 3,6°
Перерегулирование, не более | σ | 10 %
Время переходного процесса, не более, с | tпп | 16
Коэффициент режима работы | Cp | 1,3
Запас по моменту | λM | 2

Требования ТЗ к электронике:

- напряжение питания приводов — постоянное 24 В; сетевое напряжение 220 В внутрь стенда не заводится;
- тип двигателей — коллекторные ДПТ; управление — ШИМ с реверсом и торможением;
- обратные связи каждого канала: по угловому положению (магнитный энкодер) и по току якоря (датчик тока);
- аварийное отключение питания двигателя каждого канала независимо от драйвера;
- два режима работы, переключаемые одной кнопкой: полный (управление всеми звеньями от контроллера стенда) и лабораторный (ЛР), в котором студент управляет звеном со своего контроллера через внешний разъём;
- связь с ПК верхнего уровня по USB; связь со съёмным схватом по UART;
- гальваническая развязка логической части (контроллер, датчики, разъёмы студента) от силовой части (двигатели, реле);
- защита от перенапряжения и перегрузки по входу питания;
- индикация состояния каждого звена.

Параметры, не определённые заданием кафедры (точная грузоподъёмность, рабочая зона, состав электроники схвата), в работе обозначены как требующие уточнения; правдоподобные значения вместо них не подставляются.

Требуемый результат: комплект печатных плат электроники манипулятора с контурами обратной связи по току и положению, функциональная схема системы, принципиальные схемы плат, перечень элементов.

# 2 Структура электроники манипулятора

## 2.1 Функциональная схема

Функциональная схема электроники приведена на рисунке 2 (воспроизведена по текущей версии файла system/functional_scheme_A2 репозитория [1] и обновляется вместе с ним). Контроллер стенда — плата ESP32-S3 — связан с ПК по USB и управляет четырьмя одинаковыми каналами привода. Канал привода состоит из узла гальванической развязки сигналов IN1, IN2 (ШИМ 20 кГц) и RELE, драйвера ДПТ, реле аварийного отключения питания двигателя, датчика тока и реле режима, переключающих управление звеном между контроллером стенда и внешним разъёмом ЛР. Датчик положения AS5600 каждого звена подключён к контроллеру по I2C через мультиплексор TCA9548A, так как адрес датчика фиксирован.

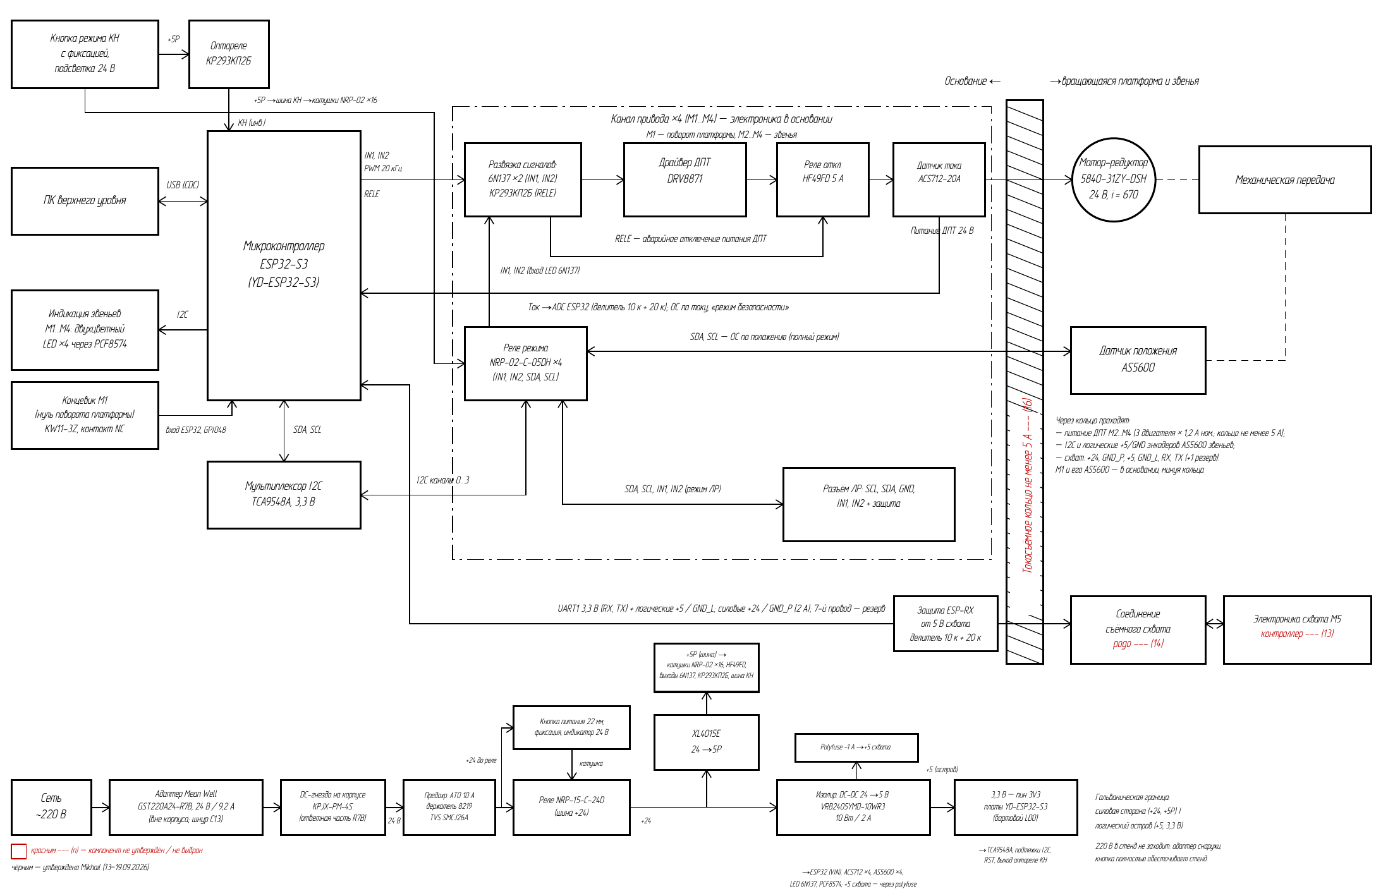
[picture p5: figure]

Рисунок 2. Функциональная схема электроники манипулятора (схема электрическая функциональная, лист А2)

Привод M1 (поворот платформы) и его энкодер находятся в основании; двигатели и энкодеры звеньев M2…M4 расположены на вращающейся платформе и подключаются через токосъёмное кольцо, через которое также проходят линии съёмного схвата M5: силовые +24 В, логические +5 В и UART. Электроника схвата (контроллер, драйвер двигателя схвата, датчики) выполняется по отдельному техническому заданию и в настоящей работе не проектируется.

## 2.2 Режимы работы и гальваническая развязка

Кнопка режима KH с фиксацией подаёт напряжение +5P на шину KH, от которой питаются катушки реле режима всех четырёх каналов: в режиме ЛР сигналы IN1, IN2 и линии SDA, SCL энкодера звена переключаются с контроллера стенда на клеммы панели ЛР. Состояние кнопки передаётся в контроллер через оптореле, что позволяет программе сбросить шину I2C и отменить команды при смене режима. Реле отключения RELE и датчик тока остаются под контролем контроллера стенда в обоих режимах, поэтому защита двигателя по току действует и при управлении от студента.

Граница гальванической развязки разделяет силовую сторону (шина +24 В, силовые +5P для катушек реле и подтяжек выходов оптронов, земля GND_P) и логический остров (+5 В и 3,3 В контроллера, датчиков, панели ЛР, земля GND_L). Границу пересекают только оптроны 6N137 (ШИМ), оптореле КР293КП2Б (статические сигналы RELE и KH), контакты реле режима, датчики тока ACS712 (встроенная изоляция измеряемой цепи) и изолированный DC-DC преобразователь логического острова. Такое разделение исключает протекание токов двигателей по земле контроллера и защищает ноутбук студента, подключённый к панели ЛР, от силовой части.

## 2.3 Разделение на печатные платы

Цепь канала привода повторяется четыре раза. Вариант одной большой платы с четырьмя копиями цепи отклонён: минимальный заказ у изготовителя составляет пять плат, ошибка в разводке канала повторялась бы четырёхкратно, а всю плату нельзя было бы разводить до выбора двигателя. Принят вариант с отдельной платой канала в четырёх экземплярах (пятая — запасная) и главной платой; состав плат приведён в таблице 3.

Таблица 3.

Разделение электроники на печатные платы

Код | Плата | Кол-во | Состав | Зависит от
CH | Канал привода | 4 + 1 зап. | 6N137 ×2, КР293КП2Б, модуль DRV8871, реле HF49FD, модуль ACS712-20A, реле NRP-02 ×4, обвязка; на плате проходит граница развязки | двигатель → драйвер, реле
MC | Главная (контроллер) | 1 | гнездо YD-ESP32-S3, TCA9548A, оптореле KH, вход концевика M1, разъём UART схвата с polyfuse на +5, разъёмы четырёх плат CH; силовых токов нет | —
PS | Питание | 1 | реле NRP-15, TVS SMCJ26A, диод катушки, модуль XL4015E, изолированный DC-DC VRB2405YMD-10WR3, LC-фильтр +5P, клеммы раздачи +24 В, разъёмы кнопок и индикатора | —
LR | Панель ЛР | 1 | клеммы четырёх групп M1…M4, защита у клемм (100 Ом, BAT54S, 1N4148), PCF8574 и двухцветные светодиоды | тип клемм
GR | Схват | 1 | по ТЗ на схват (контроллер, драйвер M5, датчики) | ТЗ схвата

Вне плат размещаются: внешний адаптер питания и сетевой шнур, DC-гнездо на корпусе, кнопка питания и кнопка KH со встроенной подсветкой 24 В, держатель предохранителя в проводе, концевой выключатель M1, двигатели, энкодеры и токосъёмное кольцо.

# 3 Выбор и расчёт элементов канала привода

## 3.1 Двигатель

Выбор двигателя выполнен по энергетическому расчёту приводов [2]; ниже приведены его исходные положения и результаты, поскольку от параметров двигателя зависят драйвер, реле отключения, датчик тока и источник питания.

### 3.1.1 Кинематическая цепь и ограничения

Кинематическая цепь принята в следующем виде. Первое звено (поворот вокруг вертикальной оси): мотор-редуктор → платформа напрямую. Звенья 2…4: мотор-редуктор → зубчато-ременная передача u = 1 → зубчато-ременная передача u = 1 → звено; КПД двух ремённых передач ηрем = 0,9 · 0,9 = 0,81. Коэффициент режима работы Cp = 1,3 (тяжёлые условия — возможны перегрузки при неправильном выполнении лабораторных работ), запас по моменту λM = 2 (таблица 2).

Со стороны электроники стенда на двигатель наложены ограничения: драйвер DRV8871 с ограничением тока 3,6 А; реле отключения на 5 А; внешний адаптер 24 В, 9,2 А на весь стенд, включая логику и подсветку. Отсюда требование: номинальный ток двигателя не более 1 А, стопорный — не более 3,5 А.

### 3.1.2 Расчёт привода первого звена

Ось вращения первого звена вертикальна, поэтому гравитационный момент на приводе отсутствует и удерживающий момент равен нулю. Нагрузка носит инерционный характер: привод разгоняет всю руку целиком, вследствие чего по требуемому моменту он оказывается наиболее нагруженным из четырёх. Расчёт выполнен для наихудшего положения — рука вытянута горизонтально на максимальный вылет 540 + 400 + 270 = 1210 мм. Звенья приняты однородными стержнями; момент инерции каждого относительно вертикальной оси определён по теореме Гюйгенса — Штейнера:

J=J_c +m d^2 ,  J_c =(m l^2)/12 (1)

где Jc — момент инерции стержня относительно собственного центра масс, d — расстояние от центра масс до оси вращения. Для звена 2, вращающегося вокруг своего конца, J = m·l²/3. Составляющие момента инерции сведены в таблице 4.

Таблица 4.

Составляющие момента инерции относительно оси первого звена

Элемент | Расчёт | J, кг·м²
Звено 2 | m2·l2²/3 = 3,5 · 0,540² / 3 | 0,340
Звено 3 | m3·l3²/12 + m3·0,740² = 1,5 · 0,400²/12 + 1,5 · 0,548 | 0,841
Звено 4 | m4·l4²/12 + m4·1,075² = 0,74 · 0,270²/12 + 0,74 · 1,156 | 0,860
Груз | mг·1,210² = 0,5 · 1,464 | 0,732
Сумма | J = J2 + J3 + J4 + Jг | 2,773

Для сравнения: момент инерции нагрузки привода четвёртого звена по записке [19] составляет 0,05 кг·м², то есть у первого привода инерция больше в 55 раз. Требуемый момент на валу первого звена

M_m =J φ″+M_(тр) =2,773⋅1+0,3≈3,1 Н·м (31 кгс·см) (2)

где Mтр = 0,3 Н·м — момент трения в опорном узле и токосъёмном кольце, принятый оценочно (около 10 % динамической составляющей; параметр требует уточнения после изготовления опоры). С запасом по методике записки:

M_(треб) =λ_M M_m =2⋅3,1=6,2 Н·м (3)

Требуемая угловая скорость и мощность:

Ω=φ'=0,4 рад/с=(0,4⋅60)/(2π)=3,82 об/мин,  P=M_m Ω=3,1⋅0,4=1,24 Вт (4)

Таким образом, по мощности привод остаётся маломощным — определяющим является момент, а не мощность двигателя.

### 3.1.3 Требования к приводу четвёртого звена

По записке [19] максимальный момент на валу четвёртого звена

M_m =J φ″+M_н =0,05⋅1+2,3=2,35 Н·м (5)

из которых 2,3 Н·м — статический момент от веса звена с грузом. С учётом КПД двух ремённых передач требуемый момент на выходном валу мотор-редуктора

M=(2,35)/(0,81)=2,90 Н·м (29,6 кгс·см) при 3,82 об/мин (6)

Требования первого и четвёртого приводов близки (3,1 и 2,9 Н·м на выходном валу), что позволяет применить один тип мотор-редуктора на все четыре звена. Требуемые моменты приводов второго и третьего звеньев отдельно не рассчитывались — в записке приведён расчёт только для четвёртого звена; они заведомо не превышают требований первого.

### 3.1.4 Проверка кандидатов и выбор мотор-редуктора

Ранее приобретённый мотор-редуктор StepperOnline FGA-43246000-G149 (24 В, 4,5 А номинал, около 20 А в стопоре) не удовлетворяет ограничениям электроники по току и в проекте не используется. Сопоставление остальных кандидатов с требованиями первого привода приведено в таблице 5.

Таблица 5.

Сопоставление кандидатов с требованиями первого привода

Параметр | Требуется | JGY-370 «4632», i = 600 | «2480», i = 670
Момент номинальный, Н·м | 3,1 (6,2 с запасом) | 1,56 | 6,87
Момент стопорный, Н·м | — | 2,94 | —
Скорость номинальная, рад/с | 0,40 | 0,79 | 0,94
Ток номинальный, А | ≤ 1,0 | 0,30 | 1,20
Запас по моменту | λM = 2 | 0,5 — не проходит | 2,2 — проходит
Цена, ₽ | — | 601 | 2184

Мотор-редуктор JGY-370 не проходит по моменту: требуемые 3,1 Н·м превышают даже его стопорный момент 2,94 Н·м. Причина не в передаточном отношении, а в мощности: максимальная механическая мощность этого семейства на 24 В составляет 1,39 Вт (при i = 340), тогда как для первого привода с запасом λM = 2 требуется около 2,5 Вт. Наиболее близкий вариант семейства, i = 1000, даёт 2,60 Н·м при 0,42 рад/с — на 16 % ниже требуемого момента и без какого-либо запаса.

Отдельно проверена возможность сохранить волновой редуктор i2 = 8 (шариковый, изготовленный 3D-печатью, КПД принят 0,8) из прежней конструкции совместно с JGY-370. Пересчёт на вал первого звена (таблица 6) показывает, что ни одно передаточное отношение не удовлетворяет одновременно требованиям 3,1 Н·м и 0,4 рад/с: где достаточен момент, не хватает скорости, и наоборот. Волновой редуктор не добавляет мощности, а только перераспределяет её между моментом и оборотами.

Таблица 6.

JGY-370 с волновым редуктором i2 = 8 на валу первого звена

i редуктора | n номинальная, об/мин | Момент на звене, Н·м | Скорость на звене, рад/с
150 | 30 | 1,26 | 0,393
200 | 22 | 3,33 | 0,288
260 | 18 | 4,21 | 0,236
340 | 15 | 5,65 | 0,196
600 | 7,5 | 9,98 | 0,098
1000 | 4 | 16,64 | 0,052

Принят червячный мотор-редуктор NFP-5840-31ZY-DSH («2480», 24 В, i = 670, двойной вал ⌀ 8 мм с фланцем) [3]; его характеристики приведены в таблице 7.

Таблица 7.

Характеристики мотор-редуктора NFP-5840-31ZY-DSH

Параметр | Обозначение | Значение
Номинальное напряжение, В | Uн | 24
Передаточное отношение червячного редуктора | i | 670
Скорость холостого хода, об/мин | n0 | 12
Номинальная скорость, об/мин (рад/с) | nн | 9 (0,94)
Номинальный момент на выходном валу, кгс·см (Н·м) | Mн | 70 (6,87)
Номинальный ток, А | Iн | ≤ 1,2
Стопорный ток, А | Iст | уточняется у поставщика (паспортные ≤ 1,6 А сомнительны)
Сопротивление и индуктивность якоря | Rя, Lя | в паспорте не указаны, определяются измерением

Запас по моменту составляет 6,87 / 3,1 = 2,2, по скорости — 0,94 / 0,4 = 2,3; ток 1,2 А укладывается в ограничения драйвера, реле и источника питания. Червячная передача является самотормозящей: звенья 2…4 удерживаются без тока при обесточивании привода, что дополнительно страхует складную конструкцию манипулятора; обратной стороной является невозможность провернуть звено вручную при калибровке. При этом двигателе волновая передача не только не нужна, но и противопоказана: момент 6,87 Н·м на её входе дал бы на выходе около 55 Н·м, чего изготовленный 3D-печатью редуктор из ABS не выдержит.

Требуют уточнения: масса и момент инерции поворотной платформы вместе с установленными на ней приводами M2…M4 (в записке данных нет; их учёт увеличит расчётный момент первого привода); момент трения в опорном узле; распространение требований φ′, φ″ на первый привод; стопорный ток мотор-редуктора «2480» и исполнение вала ⌀ 8 мм (под магнит энкодера нужен гладкий торец).

## 3.2 Драйвер двигателя

В предыдущих курсовых проектах усилитель мощности выполнялся на дискретном H-мосте (транзисторы IRFZ14/IRF100B202 с драйверами полумостов IR2101/IR2104 и цепями самоподкачки). Для тока 1,2 А при 24 В такое решение избыточно по площади и числу элементов, поэтому выбран интегральный H-мост. Требования к драйверу:

- напряжение питания силовой части 24 В с запасом не менее 1,5 по предельному напряжению;
- длительный ток не менее 1,2 А, пиковый — не менее 3,5 А;
- управление двумя логическими входами (ШИМ на одном из входов, реверс, торможение) при уровнях 3,3 В и 5 В;
- встроенное ограничение тока и защита от перегрева, перенапряжения и короткого замыкания;
- частота ШИМ не менее 20 кГц (выше слышимого диапазона).

Этим требованиям соответствует микросхема DRV8871 фирмы Texas Instruments [4], применяемая в виде готового модуля (клон платы Adafruit). Основные параметры приведены в таблице 8, назначение выводов — в таблице 9.

Таблица 8.

Основные параметры драйвера DRV8871

Параметр | Значение
Напряжение питания VM, В | 6,5…45
Пиковый ток, А | 3,6
Сопротивление открытого канала верхний + нижний ключ RDS(on), мОм | 565 (тип.)
Входы управления IN1, IN2 | логические, порог VIH ≥ 1,5 В, до 200 кГц
Ограничение тока | задаётся резистором RILIM, отключение ключей по превышению
Защиты | пониженное напряжение, перегрев (Tj ≈ 175 °C), короткое замыкание
Тепловое сопротивление RθJA, °C/Вт | ≈ 38 (корпус HSOP-8 с теплоотводящей площадкой)
Корпус | HSOP-8 (DDA) с теплоотводящей площадкой

Таблица 9.

Функционал выводов DRV8871

Номер вывода | Функциональное назначение | Условное обозначение
1 | Общий вывод | GND
2 | Вход управления 1 | IN1
3 | Вход управления 2 | IN2
4 | Резистор ограничения тока | ILIM
5 | Питание силовой части | VM
6 | Выход 1 (к обмотке двигателя) | OUT1
7 | Общий вывод | GND
8 | Выход 2 (к обмотке двигателя) | OUT2
PAD | Теплоотводящая площадка | PPAD

Логика управления: при IN1 = 1, IN2 = 0 двигатель вращается в прямом направлении, при IN1 = 0, IN2 = 1 — в обратном; при IN1 = IN2 = 0 выходы переходят в высокоомное состояние (выбег), при IN1 = IN2 = 1 оба нижних ключа открыты — динамическое торможение. Скорость задаётся подачей ШИМ на один из входов при единице на другом (торможение в паузе) или при нуле на другом (выбег в паузе).

Частота ШИМ. Пока параметры якоря выбранного двигателя не измерены, для расчёта приняты паспортные данные двигателя близкого класса (24 В, мотор-редуктор PA36-38244500-G720 [20]): сопротивление якоря Rя = 12,15 Ом, индуктивность Lя = 4,6 мГн; после измерения расчёт повторяется. Электромагнитная постоянная времени якоря:

T_э =(L_я)/(R_я)=(4,6⋅10^(-3))/(12,15)≈0,38 мс (7)

Первое условие — управляемость: период ШИМ должен быть много меньше Tэ, тогда ток якоря за период не успевает существенно измениться и двигатель реагирует на среднее напряжение, а не на отдельные импульсы:

T_(ШИМ) ≪T_э ⇒ f_(ШИМ) ≫1/(T_э)=1/(0,38⋅10^(-3))≈2,6 кГц (8)

По методике [19] это условие принимают с десятикратным запасом, откуда fШИМ ≥ 10 / Tэ ≈ 26 кГц. Второе условие — пульсации тока: за период ШИМ ток нарастает со скоростью не более Uпит/Lя, и размах пульсаций должен быть много меньше номинального тока:

ΔI=T_(ШИМ) ⋅(U_(пит))/(L_я)≪I_н ⇒ T_(ШИМ) ≪(L_я I_н)/(U_(пит))=(4,6⋅10^(-3) ⋅1,2)/24=0,23 мс (9)

f_(ШИМ) ≫1/(0,23⋅10^(-3))≈4,3 кГц (10)

Эта оценка груба — она предполагает, что ток нарастает весь период. Точнее: при коэффициенте заполнения D ток нарастает лишь долю D периода, и размах пульсаций

ΔI=(U_(пит) D (1-D))/(L_я f_(ШИМ)),  ΔI_(max) =(24⋅0,25)/(4,6⋅10^(-3) ⋅20⋅10^3)≈0,065 А (5 % I_н ) (11)

Третье условие — частота выше слышимого диапазона (≥ 16…20 кГц), чтобы обмотки не издавали свист. Четвёртое — ограничения элементов: допустимая частота входов DRV8871 до 200 кГц; задержка оптрона 6N137 (не более 75 нс) должна быть много меньше периода, чтобы не искажать коэффициент заполнения — при 20 кГц (период 50 мкс) искажение составляет не более 0,15 %. Пятое — коммутационные потери в ключах драйвера пропорциональны частоте, поэтому из допустимого диапазона выбирается нижняя граница.

Условиям управляемости (f ≫ 2,6 кГц), пульсаций (5 % Iн при D = 0,5), слышимости и быстродействия элементов одновременно удовлетворяет fШИМ = 20 кГц, TШИМ = 50 мкс. Десятикратный критерий [19] (26 кГц) при принятых параметрах выполняется с небольшим недобором; если измеренная постоянная времени Tэ окажется меньше 0,4 мс, частота поднимается до 25…30 кГц — контроллер ШИМ ESP32-S3 (LEDC) сохраняет при этом разрешение не хуже 11 бит, а потери в драйвере растут незначительно.

Тепловой расчёт. Мощность, рассеиваемая на ключах драйвера при номинальном токе:

P_(др) =I_н^2 R_(DS(on)) =1,2^2 ⋅0,565≈0,81 Вт (12)

Перегрев кристалла относительно окружающей среды:

ΔT=P_(др) R_(θJA) =0,81⋅38≈31 ^(∘) C (13)

При температуре в корпусе стенда 40 °C температура кристалла составит около 71 °C, что значительно ниже порога тепловой защиты 175 °C. При ограничении тока 3,5 А потери возрастают до 6,9 Вт, но этот режим кратковременный: программа отключает канал по сигналу датчика тока за единицы миллисекунд, а сама микросхема — по перегреву.

Ограничение тока. Порог срабатывания встроенного ограничителя задаётся резистором RILIM между выводом ILIM и общим проводом:

I_(TRIP) =64000/(R_(ILIM)) (14)

где RILIM — в омах, ITRIP — в амперах. Для требуемого предела 3,5 А:

R_(ILIM) =64000/(3,5)≈18,3 кОм

По ряду E24 принимается RILIM = 18 кОм, что даёт ITRIP = 3,56 А. На модуле Adafruit установлен резистор 30 кОм (предел около 2,1 А); у приобретённых клонов номинал требует проверки и при необходимости замены — от него зависит допустимый пусковой ток двигателя.

## 3.3 Гальваническая развязка сигналов управления

Сигналы IN1, IN2 — ШИМ 20 кГц, поэтому оптрон должен иметь время задержки распространения много меньше периода 50 мкс; фронты должны быть достаточно крутыми, чтобы не искажать коэффициент заполнения. Зададим допустимую задержку не более 1 мкс (2 % периода). Транзисторные оптроны общего назначения (PC817, КР293КП2Б) с временем переключения порядка 0,1–1 мс не подходят; выбран быстродействующий оптрон 6N137 фирмы Vishay [5] с логическим выходом (открытый коллектор) и временем задержки не более 75 нс (таблица 10).

Таблица 10.

Основные параметры оптрона 6N137

Параметр | Значение
Скорость передачи, Мбит/с | 10
Задержка распространения tPHL, tPLH, нс | ≤ 75 (тип. 48/50)
Рекомендуемый ток светодиода IF, мА | 6,3…15
Прямое падение на светодиоде VF, В | 1,4…1,7
Напряжение питания выхода VCC, В | 4,5…5,5
Выход | открытый коллектор, до 50 мА
Напряжение изоляции, В | 2500 (среднеквадратичное, 1 мин)

Резистор светодиода R1 = 220 Ом общий для управления от ESP32 (3,3 В) и от контроллера студента (3,3 или 5 В). Ток светодиода при управлении от ESP32:

I_F =(U_(вых) -V_F -U_(OL))/(R_1)=(3,3-1,45-0,1)/220≈8 мА (15)

что находится в рекомендуемом диапазоне. При управлении с 5-вольтового контроллера студента ток достигает (5 − 1,45 − 0,4) / 220 ≈ 14 мА — на границе рекомендуемых 15 мА; этот пункт отмечен в базе компонентов как требующий внимания, при испытаниях номинал может быть увеличен до 270 Ом. Ток 8 мА не превышает допустимый ток вывода ESP32-S3 (40 мА).

Выход оптрона — открытый коллектор с подтяжкой R4 = 4,7 кОм к +5P; ток через подтяжку при низком уровне (5 − 0,4) / 4,7 кОм ≈ 1 мА, время нарастания при входной ёмкости DRV8871 порядка 10 пФ — десятки наносекунд. Выход инвертирующий (светодиод включён — на входе драйвера ноль), что учитывается в программе. Полезное следствие инверсии: при отключённом контроллере студента в режиме ЛР оба светодиода погашены, на входах IN1, IN2 драйвера единицы — двигатель заторможен, а не вращается.

Статические сигналы RELE (отключение питания двигателя) и KH (состояние кнопки режима) быстродействия не требуют; для них применены оптореле КР293КП2Б из имеющегося запаса. Резистор светодиода 150 Ом обеспечивает ток около 10 мА от вывода ESP32; выходной ключ оптореле включает катушку реле отключения (24 мА при 5 В), что входит в допустимые для этого оптореле пределы коммутируемого тока.

## 3.4 Реле аварийного отключения

По требованию ТЗ питание двигателя должно отключаться независимо от драйвера — при отказе драйвера (пробой ключа), при зависании контроллера или в режиме ЛР при ошибке студента. В линию +24 В каждого канала перед драйвером включено электромагнитное реле HF49FD/005-1H11 (Hongfa) [6]: катушка 5 В, 24 мА, один нормально разомкнутый контакт на 5 А / 30 В постоянного тока. Требования: коммутируемый ток контакта не менее стопорного тока двигателя (≤ 3,5 А с учётом ограничения драйвера) — выполняется с запасом 1,4; катушка питается от +5P через оптореле, поэтому отключение выполняется на силовой стороне без пересечения границы развязки силовым током.

Реле нормально разомкнуто: двигатель получает питание только при активном сигнале RELE от контроллера. Выброс ЭДС самоиндукции катушки при выключении гасится диодом; конденсатор 0,1 мкФ по питанию оптрона ставится по рекомендации спецификации 6N137 (позиции подлежат внесению в базу компонентов).

## 3.5 Датчик тока

Датчик тока необходим для обратной связи по току якоря (контроль усилия) и для защиты двигателя и механики от перегрузки. Требования:

- диапазон измерения не менее ±3,6 А (предел ограничения драйвера) в обоих направлениях;
- гальваническая изоляция измеряемой цепи от сигнальной части, так как датчик стоит на силовой стороне, а его выход идёт в АЦП контроллера;
- выходной сигнал, согласуемый с АЦП ESP32-S3 (диапазон 0…3,1 В при ослаблении 11 дБ);
- полоса пропускания, достаточная для отслеживания среднего тока при ШИМ 20 кГц (высокочастотные пульсации подлежат подавлению).

Выбран датчик на эффекте Холла ACS712ELCTR-20A (Allegro) [7] в виде модуля; его параметры приведены в таблице 11. В отличие от версии 05B, применявшейся в предыдущих проектах, версия 20A имеет диапазон ±20 А и чувствительность 100 мВ/А, что при токах до 3,6 А использует лишь пятую часть диапазона, но исключает выход датчика из линейной зоны при пусковых токах.

Таблица 11.

Основные характеристики ACS712ELCTR-20A

Обозначение | Минимальное значение | Типовое значение | Максимальное значение
VCC, В | 4,5 | 5,0 | 5,5
IP, А | −20 | — | +20
Чувствительность, мВ/А | — | 100 | —
VIOUT(Q) (ток 0), В | — | VCC/2 = 2,5 | —
Полоса пропускания, кГц | — | 80 | —
Ток потребления ICC, мА | — | 10 | 13
Напряжение изоляции, В | — | 2100 (среднеквадратичное) | —
Допустимая ёмкость нагрузки, нФ | — | — | 10

Выход датчика ратиометричен питанию 5 В и при нулевом токе равен 2,5 В; при токе ±3,6 А он изменяется в пределах 2,14…2,86 В, а при полном диапазоне ±20 А — 0,5…4,5 В. Для согласования с АЦП ESP32-S3, вход которого не допускает напряжений выше 3,3 В, установлен резистивный делитель R6 = 10 кОм, R7 = 20 кОм с коэффициентом передачи

k_д =(R_7)/(R_6 +R_7)=20/(10+20)=0,667 (16)

После делителя нулевому току соответствует 1,67 В, номинальному току 1,2 А — 1,75 В, пределу +3,6 А — 1,91 В, а полному диапазону +20 А — 3,0 В, то есть при любом токе напряжение на входе АЦП не превышает допустимого. Чувствительность по входу АЦП составляет 66,7 мВ/А; при разрядности 12 бит и диапазоне 3,1 В цена деления АЦП равна 0,76 мВ, что соответствует разрешению около 11 мА. Шум датчика (около 20 мВ среднеквадратичных) соответствует 0,2 А и подавляется усреднением.

Конденсатор C1 = 100 нФ включён в среднюю точку делителя, а не на выход датчика: допустимая ёмкость нагрузки ACS712 не превышает 10 нФ. Постоянная времени фильтра и частота среза:

τ=(R_6 ∥R_7 ) C_1 =6,67⋅10^3 ⋅0,1⋅10^(-6) =0,67 мс,  f_с =1/(2πτ)≈240 Гц (17)

Фильтр усредняет пульсации ШИМ 20 кГц (ослабление около 38 дБ) и одновременно снижает выходное сопротивление источника сигнала для АЦП до 6,7 кОм, что требуется для корректной работы выборки-хранения АЦП ESP32-S3. Полоса 240 Гц достаточна для реакции защиты на превышение тока за единицы миллисекунд. Так как нулевой уровень датчика привязан к напряжению +5 В острова, программа калибрует ноль каждого канала при старте (при разомкнутом реле отключения).

## 3.6 Датчик углового положения

Для измерения угла звена в диапазоне 0…360° выбран магнитный энкодер AS5600 (ams OSRAM) [8] в виде модуля с диаметрально намагниченным магнитом, устанавливаемым на торце вала мотор-редуктора. Датчик бесконтактный, разрешение 12 бит (4096 положений на оборот, 0,088°), что многократно превосходит требование к статической ошибке 3,6°; интерфейс I2C позволяет передавать данные с вращающейся платформы через токосъёмное кольцо без искажений, характерных для аналогового сигнала. Назначение выводов приведено в таблице 12, основные характеристики — в таблице 13.

Таблица 12.

Функционал выводов AS5600

Номер вывода | Функциональное назначение | Условное обозначение
1 | Вход питания 5 В | VDD5V
2 | Вход/выход питания 3,3 В (внутренний LDO) | VDD3V3
3 | Аналоговый / ШИМ выход положения | OUT
4 | Общий | GND
5 | Вход программирования | PGO
6 | Линия данных I2C | SDA
7 | Линия тактирования I2C | SCL
8 | Вход задания направления отсчёта | DIR

Таблица 13.

Основные характеристики AS5600

Параметр | Значение
Напряжение питания, В | 3,3 (VDD3V3) или 5,0 (VDD5V)
Ток потребления, мА | 6,5 (тип.)
Разрешение, бит | 12
Адрес I2C | 0x36 (фиксированный)
Частота I2C, кГц | до 1000
Магнит | диаметрально намагниченный, ⌀ 6 мм, зазор 0,5…3 мм

Адрес датчика фиксирован, поэтому четыре энкодера не могут находиться на одной шине — они подключены к каналам 0…3 мультиплексора TCA9548A (п. 4.2). Линии SDA, SCL энкодера на плате канала проходят через два реле режима: в полном режиме они соединены с каналом мультиплексора, в режиме ЛР — с клеммами панели, чтобы студент читал положение звена своим контроллером. Энкодер питается от логического острова. Подтяжки I2C на модуле (типично 10 кОм) подлежат проверке на конкретном модуле.

## 3.7 Реле режима и разъём лабораторных работ

Переключение управления звеном между контроллером стенда и разъёмом студента выполняют четыре реле NRP-02-C-05DH (NCR) на канал: по одному на линии IN1, IN2, SDA, SCL. Реле имеет катушку 5 В (около 40 мА) и переключающий контакт 3 А, что для логических сигналов избыточно по току, но обеспечивает полное отключение линий студента в полном режиме и не требует активных элементов на логическом острове. Катушки всех 16 реле питаются от шины KH (+5P, силовая сторона), контакты находятся в цепях острова — реле, как и оптроны, стоят на границе развязки. Суммарный ток катушек в режиме ЛР 16 × 40 = 640 мА учитывается при расчёте источника +5P (раздел 5).

Разъём внешнего управления звеном на панели ЛР содержит пять клемм: SCL, SDA, GND (логическая земля), IN1, IN2; питание на разъём не выводится — студент питает свой контроллер сам. Приняты комбинированные приборные клеммы (винт и гнездо «банан» 4 мм), конкретная модель выбирается при закупке. Так как к разъёму подключается внешнее оборудование, у клемм установлена защита: последовательные резисторы 100 Ом и ограничители BAT54S (сборка диодов Шоттки на 3,3 В и GND) на линиях SDA, SCL; встречные диоды 1N4148 на линиях IN1, IN2 защищают светодиоды оптронов от отрицательного напряжения и переполюсовки. Резисторы 100 Ом при подтяжках I2C 4,7 кОм не нарушают уровни шины (падение при токе 0,7 мА — 70 мВ) и ограничивают ток через диоды при подаче на клемму напряжения до 12 В величиной (12 − 3,6) / 100 ≈ 84 мА, что не превышает допустимого импульсного тока BAT54S.

# 4 Выбор микроконтроллера и периферии

## 4.1 Требования и выбор микроконтроллера

Микроконтроллер выполняет корректирующие устройства четырёх контуров положения и тока, формирует сигналы ШИМ, опрашивает датчики и обменивается данными с ПК и схватом. Потребность в линиях ввода-вывода сведена в таблице 14.

Таблица 14.

Потребность в линиях ввода-вывода

Назначение | Линий | Тип
ШИМ IN1, IN2 четырёх каналов | 8 | выходы таймера ШИМ
Сигналы RELE четырёх каналов | 4 | цифровые выходы
Сигналы CURR четырёх датчиков тока | 4 | входы АЦП
Шина I2C (SDA, SCL) | 2 | I2C
Адрес и сброс мультиплексора (A0, A1, RST) | 3 | цифровые выходы
Состояние кнопки режима KH | 1 | цифровой вход
Концевой выключатель M1 | 1 | цифровой вход с прерыванием
UART схвата (RX, TX) | 2 | UART
Связь с ПК | 2 | USB
Итого | 27 | —

Дополнительные требования: не менее восьми аппаратных каналов ШИМ с частотой 20 кГц и разрешением не хуже 10 бит; не менее четырёх каналов АЦП с разрядностью 12 бит; два UART (отладочный и схвата); встроенный USB для связи с ПК без внешнего моста; вычислительная производительность, достаточная для четырёх контуров регулирования с частотой 1 кГц; доступность модуля с обвязкой, документации и среды разработки.

В предыдущих проектах применялись микроконтроллеры STM32F103/STM32F407; для настоящей работы выбран ESP32-S3 (Espressif) [9] в виде отладочной платы YD-ESP32-S3 N16R8 (клон ESP32-S3-DevKitC-1): двухъядерный процессор 240 МГц, 45 линий GPIO, 8 каналов ШИМ (LEDC) с разрешением до 14 бит на частоте 20 кГц, два АЦП по 10 каналов с разрядностью 12 бит, два I2C, три UART, встроенный USB-OTG. Беспроводные интерфейсы в проекте не используются. Плата содержит стабилизатор 3,3 В (LDO, до 1 А), мост USB-UART CH343 (резервный канал связи с ПК) и кнопки BOOT/RESET; на главную плату она устанавливается в гнездо на штыревых разъёмах. Плата питается напряжением +5 В логического острова через вывод VIN; её стабилизатор 3,3 В является источником логического напряжения для мультиплексора, подтяжек и светодиодов оптронов (отдельный преобразователь 5 → 3,3 В не требуется).

Принятое распределение выводов приведено в таблице 15. Выводы 0, 45, 46 (strapping) и 35…37 (PSRAM модуля N16R8) не используются; линии АЦП назначены на входы ADC1 (GPIO 1…10), так как ADC2 недоступен при некоторых режимах работы.

Таблица 15.

Распределение выводов ESP32-S3

Сигнал | M1 | M2 | M3 | M4
IN1 (ШИМ) | GPIO10 | GPIO12 | GPIO14 | GPIO16
IN2 (ШИМ) | GPIO11 | GPIO13 | GPIO15 | GPIO17
CURR (АЦП) | GPIO4 (ADC1_3) | GPIO5 (ADC1_4) | GPIO6 (ADC1_5) | GPIO7 (ADC1_6)
RELE | GPIO18 | GPIO21 | GPIO39 | GPIO40
SDA / SCL шины I2C | GPIO8 / GPIO9
Мультиплексор A0 / A1 / RST | GPIO47 / GPIO38 / GPIO42
Кнопка KH (через оптореле) | GPIO41
Концевик M1 | GPIO48
UART1 схвата RX / TX | GPIO1 / GPIO2
USB к ПК | GPIO19 / GPIO20 (встроенный USB-CDC)
Резерв | GPIO3, GPIO43 / GPIO44 (UART0, CH343)

Полученная в таблице 14 потребность в 27 линиях удовлетворяется с резервом в три линии. Распределение выводов принято как рабочее и помечено в базе компонентов как требующее проверки при отладке.

## 4.2 Мультиплексор I2C

Четыре энкодера AS5600 с одинаковым адресом 0x36 подключены через восьмиканальный коммутатор шины I2C TCA9548A (Texas Instruments) [10] в виде модуля CJMCU-9548; используются каналы 0…3. Микросхема питается от 3,3 В, а не от 5 В: порог входов 0,7·VCC при питании 5 В составил бы 3,5 В, и уровни ESP32 не распознавались бы. Адрес мультиплексора задаётся входами A0, A1 от ESP32 (A2 на общем проводе), что позволяет программно исключить конфликт адресов с расширителем PCF8574; вход RST подтянут к 3,3 В резистором 10 кОм и соединён с GPIO42 для аппаратного сброса шины при смене режима.

Шина работает в стандартном режиме 100 кГц. Подтяжки главной шины R = 4,7 кОм к 3,3 В (на модуле ESP32 подтяжек нет). Ток через подтяжку при низком уровне

I_п =(3,3)/(4,7⋅10^3)≈0,7 мА<3 мА (18)

не превышает допустимого тока выходов I2C. Время нарастания при суммарной ёмкости шины не более 200 пФ (плата MC, четыре шлейфа к платам CH):

t_r ≈0,85 R C_ш =0,85⋅4,7⋅10^3 ⋅200⋅10^(-12) ≈0,8 мкс<1 мкс (19)

что удовлетворяет требованию стандартного режима. Мультиплексор выполняет также согласование уровней: сторона энкодера может иметь подтяжки к 5 В при питании модуля AS5600 от 5 В.

## 4.3 Прочие узлы главной платы и панели

Состояние кнопки режима KH передаётся в ESP32 через оптореле КР293КП2Б: светодиод питается от шины KH (+5P) через резистор 470 Ом (около 8 мА), выходной ключ замыкает вход GPIO41 на GND_L; вход подтянут к 3,3 В резистором 10 кОм (сигнал инверсный, учитывается в программе). Шина KH подтянута к GND_P резистором 1 кОм, чтобы при разомкнутой кнопке катушки реле не оставались под плавающим потенциалом.

Концевой выключатель M1 (микропереключатель с рычагом типа KW11-3Z, контакт NC на GND_L) служит опорной меткой нуля поворота платформы; обвязка — подтяжка 10 кОм к 3,3 В и конденсатор 100 нФ для подавления дребезга (постоянная времени 1 мс), обработка по прерыванию. На звеньях M2…M4 концевики не ставятся: пределы поворота контролируются программно по показаниям энкодеров и по току.

Индикация состояния звеньев выполнена двухцветными светодиодами (зелёный — норма, красный — ограничение по току или отключение реле) на панели ЛР; светодиоды управляются восьмиразрядным расширителем портов PCF8574 (NXP) [11] на шине I2C, а не непосредственно выводами ESP32 — так экономится восемь линий контроллера. Аноды светодиодов подключены к 3,3 В, катоды — к выходам расширителя (зажигание нулём, выход PCF8574 принимает до 25 мА). Ток светодиода при резисторе 150 Ом и прямом падении около 2 В:

I_(св) =(3,3-2,0)/150≈8,7 мА (20)

Восемь выходов расширителя заняты полностью; для индикации режима или аварии потребуется второй PCF8574 либо PCF8575.

Связь со схватом — UART1 (3,3 В, RX/TX) плюс логическое питание +5 В острова через самовосстанавливающийся предохранитель на 1 А и силовое +24 В от платы питания. Так как контроллер схвата ещё не выбран и может оказаться 5-вольтовым, вход ESP-RX защищён делителем 10 кОм / 20 кОм (5 → 3,3 В); при переходе схвата на 3,3 В делитель заменяется перемычкой. Связь с ПК — встроенный USB ESP32-S3 (GPIO19/20, класс CDC); мост CH343 платы (UART0) оставлен как резервный канал.

# 5 Расчёт системы электропитания

## 5.1 Структура питания

Принята «ноутбучная» схема: сетевое напряжение в стенд не заходит, питание 24 В поступает от внешнего адаптера Mean Well GST220A24-R7B (24 В, 9,2 А, 221 Вт) [12] через панельное гнездо KPJX-PM-4S (4-контактный power mini-DIN, ответная часть к штекеру R7B, 7,5 А на контакт при двух контактах на полюс), предохранитель 10 А и реле включения стенда NRP-15-C-24D на шину +24 В. Кнопка питания с фиксацией коммутирует только катушку реле (39 мА), а не ток шины; её подсветка 24 В питается с выхода реле и служит индикатором наличия +24 В.

От шины +24 В питаются четыре канала привода и схват (силовое напряжение), а также два преобразователя: понижающий модуль XL4015E 24 → 5 В (+5P, силовая сторона: катушки реле режима и отключения, подтяжки выходов оптронов, шина KH) и изолированный DC-DC преобразователь Mornsun VRB2405YMD-10WR3 24 → 5 В, 10 Вт (логический остров: плата ESP32-S3, датчики, панель ЛР, логика схвата). Напряжение 3,3 В логики снимается с бортового стабилизатора платы ESP32-S3. Ступени 24 → 12 В и 12 → 5 В из прежней схемы исключены: драйвер DRV8871 питается непосредственно от 24 В, а два преобразователя непосредственно от шины имеют лучший КПД, чем цепочка.

В отличие от предыдущих проектов, где преобразователи проектировались на микросхемах LM2596/LM2672 с расчётом дросселей, здесь применены готовые модули с гарантированными изготовителем параметрами; расчёт сводится к балансу токов, проверке запасов и расчёту выходного фильтра.

## 5.2 Баланс токов шины 24 В

Потребители шины +24 В и их токи сведены в таблице 16. Входные токи преобразователей определены через мощность нагрузки и КПД по формуле

I_(вх) =(U_(вых) I_(вых))/(U_(вх) η) (21)

Таблица 16.

Баланс токов шины +24 В

Потребитель | Режим | Ток, А
Двигатели M1…M4, номинальный ток 1,2 А | 4 × 1,2 | 4,80
Двигатель схвата M5 (по ТЗ схвата, до 2 А) | — | до 2,00
Модуль XL4015E (+5P, 1 А при 5 В, η ≈ 0,9) | 5 · 1 / (24 · 0,9) | 0,23
Изолированный DC-DC VRB2405YMD (2 А при 5 В, η ≈ 0,85) | 5 · 2 / (24 · 0,85) | 0,49
Катушка реле NRP-15, подсветка кнопок, индикатор | — | 0,10
Итого в номинальном режиме | | 7,62
Итого без схвата | | 5,62

Адаптер 9,2 А обеспечивает номинальный режим с запасом 1,2 при работающем схвате и 1,6 без него. Стопор одного звена (3,5 А по ограничению драйвера) при трёх остальных в номинале даёт 3,5 + 3 · 1,2 + 0,8 = 7,9 А без схвата — в пределах адаптера; одновременный стопор нескольких звеньев рабочим режимом не является: программа отключает канал по датчику тока за единицы миллисекунд, а адаптер имеет собственную защиту от перегрузки.

## 5.3 Источник +5P и фильтр

Потребители силовых +5 В (таблица 17) — в основном катушки реле; наибольший ток возникает в режиме ЛР, когда включены все 16 реле режима.

Таблица 17.

Потребители шины +5P

Потребитель | Количество | Ток, мА
Катушки реле режима NRP-02 (режим ЛР) | 16 × 40 | 640
Катушки реле отключения HF49FD | 4 × 24 | 96
Подтяжки выходов 6N137 (4,7 кОм) | 8 × 1 | 8
Светодиод оптореле KH и индикатор «+5P есть» | — | 30
Итого | | ≈ 780

Модуль XL4015E рассчитан на выходной ток до 5 А, то есть загружен менее чем на 20 %, что обеспечивает низкий нагрев; выходное напряжение выставляется подстроечным резистором модуля на 5,0 В и фиксируется. Собственные пульсации модуля (частота преобразования 180 кГц, размах до 50 мВ) подавляются дополнительным LC-фильтром L1 = 22 мкГн (Talema DPO-3.0-22, 3 А, 50 мОм), C1 = 470 мкФ, C2 = 100 нФ, установленным вне петли обратной связи модуля. Частота среза фильтра:

f_0 =1/(2π√(L_1 C_1))=1/(2π√(22⋅10^(-6) ⋅470⋅10^(-6)))≈1,6 кГц (22)

Ослабление на частоте преобразования

A=((f_(пр))/(f_0))^2 =(180/(1,6))^2 ≈1,3⋅10^4 (82 дБ) (23)

то есть пульсации на шине +5P снижаются до долей милливольта, а реле и оптроны не передают помехи преобразователя на логический остров. Падение напряжения на активном сопротивлении дросселя при токе 1 А — 50 мВ, что допустимо для катушек реле (диапазон срабатывания NRP-02 от 3,75 В). Дроссель с током насыщения 3 А работает без насыщения с запасом 3,8.

## 5.4 Источник логического острова

Потребители изолированных +5 В приведены в таблице 18. Ток платы ESP32-S3 принят по спецификации модуля с запасом на пики; ток схвата ограничен полимерным предохранителем 1 А в основании, и это требование внесено в ТЗ схвата.

Таблица 18.

Потребители логического острова +5 В

Потребитель | Количество | Ток, мА
Плата YD-ESP32-S3 (модуль без Wi-Fi, LDO 3,3 В, CH343) | 1 | до 500
Энкодеры AS5600 | 4 × 6,5 | 26
Датчики тока ACS712 (сигнальная часть) | 4 × 13 | 52
Мультиплексор TCA9548A, подтяжки | — | 5
Светодиоды 6N137 (через выводы ESP32, из 3,3 В) | 8 × 8 | 64
Светодиоды оптореле RELE и KH | 5 × 10 | 50
Расширитель PCF8574 и индикаторы звеньев | 4 × 8,7 | 40
Логика схвата (по ТЗ, через polyfuse) | — | до 1000
Итого | | ≈ 1740

Преобразователь VRB2405YMD-10WR3 [13] (стабилизированный выход 5 В, 2 А, изоляция 1,5 кВ, КПД около 85 %) покрывает нагрузку с запасом 15 % в худшем случае и более чем двукратным при типовом потреблении схвата. Из потребителей 3,3 В (модуль ESP32, светодиоды оптронов, мультиплексор, индикаторы — до 650 мА) следует, что бортовой стабилизатор платы (1 А) также загружен допустимо; рассеиваемая на нём мощность при типовом токе 250 мА составляет (5 − 3,3) · 0,25 ≈ 0,4 Вт.

Ранее рассматривавшийся вариант питания острова от четырёх модулей B0505S-1W отклонён: бюджет острова с учётом схвата превышает их суммарную мощность, а параллельное включение нестабилизированных модулей нецелесообразно.

## 5.5 Защита входа питания

Предохранитель. Полный ток стенда не превышает 9,2 А (предел адаптера); выбран флажковый предохранитель ATO 10 А в держателе на провод, включённый между DC-гнездом и реле. Участок гнездо — предохранитель — реле выполнен проводом 18 AWG (0,82 мм², допустимый ток свыше 10 А); отводы +24 В к платам каналов и схвату — проводом 20–22 AWG.

Защита от перенапряжения. Параллельно шине после предохранителя установлен однонаправленный TVS-диод SMCJ26A (1500 Вт) [14]: напряжение отсечки 26 В выше рабочего 24 В (допуск адаптера ±1 %), напряжение пробоя 28,9…31,9 В, напряжение ограничения не более 42,1 В при импульсном токе 35,7 А. Предельные напряжения потребителей — 45 В у DRV8871, 38 В у XL4015E, 36 В у VRB2405 — не превышаются при реалистичных энергиях выбросов (десятки микроджоулей от индуктивности проводов и обмоток при коммутации реле), когда ток через TVS составляет единицы ампер и напряжение ограничения близко к 32…34 В. Ранее предложенный SMBJ28A отклонён: его напряжение ограничения около 45 В превышает предел XL4015E. Защита от переполюсовки обеспечивается конструкцией: адаптер с несъёмным кабелем и штекером R7B подключается к гнезду KPJX-PM-4S только в одном положении.

Реле включения стенда NRP-15-C-24D [15]: контакт 20 А / 28 В постоянного тока при токе шины до 9,2 А (запас 2,2), катушка 24 В, 619 Ом, 39 мА. Параллельно катушке включён диод 1N4007 (катодом к +24 В), гасящий ЭДС самоиндукции при размыкании и берегущий контакт кнопки питания. При выключении кнопки реле обесточивает всю шину +24 В, включая оба преобразователя, — стенд полностью обесточивается.

# 6 Разработка печатных плат

## 6.1 Технология изготовления

Платы изготавливаются по технологии производителя «Резонит» [16] по образцу чертежа кафедры; принятые параметры приведены в таблице 19. Число слоёв — два: при принятом разделении на платы плотность монтажа невысока (выводные компоненты и модули), а двусторонняя плата дешевле и допускает ручной ремонт. Класс точности 3 по ГОСТ 23751-86 [17] выбран как минимально достаточный: минимальные проводник и зазор 0,3 мм заведомо шире принятых в проекте 0,5 мм.

Таблица 19.

Технология изготовления печатных плат

Параметр | Значение
Число слоёв | 2 (F.Cu, B.Cu)
Материал, толщина | FR-4, 1,6 мм ± 10 %
Медь | фольга 18 мкм, после металлизации ≈ 35 мкм; финиш HAL бессвинцовый
Паяльная маска | PSR-4000 H85 или аналог
Класс точности | 3 по ГОСТ 23751-86
Минимальные проводник / зазор | 0,3 / 0,3 мм (завод); 0,5 / 0,5 мм принято в проекте
Переходные отверстия | ⌀ 1,2 мм, сверло 0,6 мм
Шаг сетки | 1 мм (0,5 мм для компонентов с дюймовым шагом выводов)
Крепление | 4 отверстия ⌀ 3,2 мм под винты М3
Технические требования | по ГОСТ Р 55693-2013

## 6.2 Ширина проводников

Ширина проводника определяется по формуле IPC-2221 [18] для наружного слоя при допустимом перегреве ΔT = 20 °C:

I=k ΔT^(0,44) A^(0,725) ,  A=(I/(k ΔT^(0,44)))^(1/0,725) ,  b=A/h (24)

где I — ток, А; k = 0,048 для наружных слоёв; A — сечение проводника, мил²; h = 1,38 мил — толщина меди 35 мкм; b — ширина проводника. Для тока 9,2 А входной цепи платы PS:

A=((9,2)/(0,048⋅20^(0,44)))^(1/0,725) ≈228 мил^2 ,  b=228/(1,38)≈165 мил≈4,2 мм

Результаты для остальных цепей и принятые в проекте ширины сведены в таблице 20; принятые значения превышают расчётные не менее чем в 1,4 раза, а для сигнальных цепей ширина 0,8 мм выбрана из технологических соображений (ручная пайка, ремонт).

Таблица 20.

Ширина проводников

Цепь | Ток, А | Расчётная ширина, мм | Принято, мм | Плата
+24V_IN: гнездо → TVS → реле; реле → зона +24 В | 9,2 | 4,2 | 6,0 (дорожка) / зона | PS
Отводы +24 В на каналы и схват | ≤ 3 | 0,9 | 1,5…3,0 | PS
+5P: модуль → фильтр → разъём | ≤ 2 | 0,5 | 2,0 | PS
Остров +5V_L, GND_L | ≤ 2 | 0,5 | 1,5 | PS
+24V, +24V_M (цепь двигателя) | ≤ 3,5 | 1,1 | 1,5 | CH
+5P, +5V_L, KH, земли | ≤ 0,7 | 0,15 | 1,0 | CH, MC
Сигнальные цепи, катушки реле | < 0,1 | 0,03 | 0,8 | все
GND_P | — | — | полигон B.Cu | PS, CH

## 6.3 Зазоры и граница гальванической развязки

Максимальная разность потенциалов на платах — 24 В. По IPC-2221 для наружных проводников без покрытия при напряжении 16…30 В минимальный зазор составляет 0,1 мм, по классу 3 ГОСТ 23751-86 — 0,25 мм; в проекте принят единый зазор 0,5 мм, упрощающий изготовление и ремонт. Между медью логического острова и силовой стороны на платах PS и CH выдерживается расстояние не менее 2 мм, что для функциональной изоляции цепей 24 В многократно превышает требуемое и одновременно защищает от случайных перемычек при пайке; под изолирующим преобразователем и оптронами на обеих сторонах платы заданы запреты заливки полигонов, граница показана штрихпунктирной линией на шелкографии и проверяется скриптом. Земли GND_P и GND_L на платах не соединяются.

## 6.4 Схемы и компоновка плат

Принципиальные схемы плат выполнены в KiCad 10 по ГОСТ 2.702, 2.710, 2.728–2.756 на листах с рамкой и основной надписью по ГОСТ 2.104, шрифтом по ГОСТ 2.304.

Общие правила компоновки: расстановка ведётся функциональными узлами, а не поэлементно; фильтрующие конденсаторы — вплотную к выводам микросхем и модулей; силовые проводники — минимальной длины; вокруг каждого крепёжного отверстия оставлена свободная от меди зона ⌀ 8 мм; изломы проводников выполняются под 45°; шелкография не заходит на контактные площадки; проверяются высота компонентов и доступ паяльником при сборке. Крепление — отверстия ⌀ 3,2 мм под винты М3: по четыре на платах PS, MC и CH и шесть на вытянутой плате LR. Ревизия платы наносится на шелкографию, а на каждую ревизию, отправленную в производство, ставится тег в репозитории, что связывает результаты испытаний с конкретной версией манипулятора.

# Заключение

В ходе курсового проекта были выполнены следующие задачи:

- проведено энергетический расчёт и выбран мотор-редуктор звеньев и, исходя из его параметров, выбраны и рассчитаны элементы канала привода: интегральный драйвер ДПТ, быстродействующая гальваническая развязка сигналов ШИМ, реле аварийного отключения, датчик тока с согласующим делителем и фильтром, магнитный энкодер;
- выбран микроконтроллер ESP32-S3, распределены его выводы, рассчитана шина I2C с мультиплексором, спроектированы узлы переключения режима, индикации и связи со схватом;
- рассчитана система электропитания: баланс токов шины 24 В, силового источника +5P и изолированного логического острова, LC-фильтр и элементы защиты входа;
- принято разделение электроники на пять печатных плат, определена технология изготовления, рассчитаны ширины проводников и зазоры, разработаны принципиальные схемы плат CH, PS, MC, LR.

Отличительными решениями проекта являются модульность (плата канала привода в четырёх экземплярах с запасной), полная гальваническая развязка логической части от силовой, два режима работы с независимой от режима защитой двигателей по току и ведение всех данных о компонентах в единой базе, из которой составляются схемы и платы.

# Список источников

1. Репозиторий проекта «Учебный манипулятор», подпроект electronics (KiCad-проекты плат, база компонентов bom/Component_Base.xlsx, обоснование разделения на платы docs/board-partition.md). МГТУ им. Н.Э. Баумана, кафедра «Робототехнические системы и мехатроника», 2026.

2. Энергетический расчёт приводов учебного манипулятора. Выбор мотор-редукторов звеньев M1…M4 (docs/drive-energy-calc.docx). МГТУ им. Н.Э. Баумана, группа СМ7-21М, 19.09.2026.

3. Мотор-редуктор червячный NFP-5840-31ZY-DSH, 24 В, i = 670 // Яндекс Маркет: [сайт]. – URL: https://market.yandex.ru/cc/B6zFNi (дата обращения: 30.05.2026).

4. DRV8871 3.6-A Brushed DC Motor Driver With Internal Current Sense and Regulation: спецификация // Texas Instruments: [офиц. сайт]. – URL: https://www.ti.com/lit/ds/symlink/drv8871.pdf (дата обращения: 03.09.2026).

5. 6N137, VO2601, VO2611, VO2630, VO2631, VO4661 High Speed Optocoupler: спецификация // Vishay: [офиц. сайт]. – URL: https://www.vishay.com/docs/84732/6n137.pdf (дата обращения: 05.09.2026).

6. HF49FD Subminiature Power Relay: спецификация // Hongfa: [офиц. сайт]. – URL: https://www.hongfa.com (дата обращения: 30.09.2026).

7. ACS712 Fully Integrated, Hall-Effect-Based Linear Current Sensor IC: спецификация // Allegro MicroSystems: [офиц. сайт]. – URL: https://www.allegromicro.com/-/media/files/datasheets/acs712-datasheet.ashx (дата обращения: 04.09.2026).

8. AS5600 12-Bit Programmable Contactless Potentiometer: спецификация // ams OSRAM: [офиц. сайт]. – URL: https://ams.com/documents/20143/36005/AS5600_DS000365_5-00.pdf (дата обращения: 03.09.2026).

9. ESP32-S3 Series Datasheet // Espressif Systems: [офиц. сайт]. – URL: https://www.espressif.com/sites/default/files/documentation/esp32-s3_datasheet_en.pdf (дата обращения: 03.09.2026).

10. TCA9548A Low-Voltage 8-Channel I2C Switch with Reset: спецификация // Texas Instruments: [офиц. сайт]. – URL: https://www.ti.com/lit/ds/symlink/tca9548a.pdf (дата обращения: 04.09.2026).

11. PCF8574; PCF8574A Remote 8-bit I/O expander for I2C-bus with interrupt: спецификация // NXP: [офиц. сайт]. – URL: https://www.nxp.com/docs/en/data-sheet/PCF8574_PCF8574A.pdf (дата обращения: 03.09.2026).

12. GST220A 220W Single Output Industrial Adaptor: спецификация // Mean Well: [офиц. сайт]. – URL: https://www.meanwell.com/webapp/product/search.aspx?prod=GST220A (дата обращения: 04.09.2026).

13. VRB_YMD-10WR3 Series 10W Isolated Wide Input DC/DC Converter: спецификация // Mornsun: [офиц. сайт]. – URL: https://www.mornsun-power.com (дата обращения: 05.09.2026).

14. SMCJ Series 1500W Transient Voltage Suppressor: спецификация // Littelfuse: [офиц. сайт]. – URL: https://www.littelfuse.com/products/tvs-diodes/surface-mount/smcj (дата обращения: 05.09.2026).

15. NRP-15 Power Relay: спецификация // NCR Electronics: [офиц. сайт]. – URL: https://www.ncr.hk (дата обращения: 30.09.2026).

16. Технологические возможности производства печатных плат // Резонит: [офиц. сайт]. – URL: https://www.rezonit.ru/directory/tekhnologicheskie-osobennosti-proizvodstva/ (дата обращения: 05.09.2026).

17. ГОСТ 23751-86. Платы печатные. Основные параметры конструкции. – М.: Издательство стандартов, 1986.

18. IPC-2221B. Generic Standard on Printed Board Design. – IPC, 2012.

19. Засорин Е.М. Разработка привода четвёртого звена учебно-лабораторного манипулятора: расчётно-пояснительная записка. – МГТУ им. Н.Э. Баумана, 2025.

20. Паспортные данные двигателя PA36-38244500-G720 // stepperonline.ru: [офиц. сайт]. – URL: https://www.stepperonline.ru/kollektornyy-motor-reduktor-24-v-postoyannoho-toka-30-khsm46-obmyn-s-planetarnym-reduktorom-7201 (дата обращения: 30.05.2026).

# Приложение А

Перечень основных элементов электроники

(по базе компонентов, статус «Утверждено»)

Таблица 21.

Перечень элементов

ID базы | Наименование | Кол-во | Размещение
E-001 | Адаптер питания Mean Well GST220A24-R7B, 24 В, 9,2 А | 1 | вне корпуса
E-014 | DC-гнездо Kycon KPJX-PM-4S, 4-pin power mini-DIN | 1 | панель
E-003 | Предохранитель ATO 10 А, держатель на провод | 1 | корпус
E-013 | Реле шины 24 В NRP-15-C-24D | 1 | PS
E-015 | Диод 1N4007 (катушка реле) | 1 | PS
E-004 | TVS SMCJ26A | 1 | PS
E-002 | Кнопка питания 22 мм с фиксацией, подсветка 24 В | 1 | панель
E-007 | Модуль DC-DC XL4015E 24 → 5 В (+5P) | 1 | PS
E-012, E-093, E-094 | Фильтр +5P: дроссель DPO-3.0-22 22 мкГн; 470 мкФ 16 В; 0,1 мкФ | 1 + 1 + 1 | PS
E-010 | Изолированный DC-DC Mornsun VRB2405YMD-10WR3, 10 Вт | 1 | PS
E-008, E-009 | Индикатор «+5P есть», резистор 150 Ом | 1 + 1 | панель / PS
E-017 | Клеммник DG301-5.0-02P-12, 15 А | 6 | PS
E-018, E-019, E-092 | Разъёмы JST B2B-XH-A, B2P-VH, B4B-XH-A | 2 + 2 + 1 | PS
E-020 | Плата контроллера YD-ESP32-S3 N16R8 | 1 | MC
E-021 | Подтяжки I2C 4,7 кОм | 2 | MC
E-022, E-023 | Мультиплексор I2C CJMCU-9548 (TCA9548A); подтяжка RST 10 кОм | 1 + 1 | MC
E-024 | Кнопка режима KH EKF S-Pro67, 19 мм, с фиксатором, подсветка 24 В | 1 | панель
E-025 | Подтяжка шины KH 1 кОм | 1 | MC
E-026, E-027 | Оптореле KH КР293КП2Б; резисторы 470 Ом, 10 кОм | 1 + 2 | MC
E-090, E-091 | Концевик M1 KW11-3Z; обвязка 10 кОм + 100 нФ | 1 + 2 | основание / MC
E-073, E-083 | Делитель ESP-RX 10 к / 20 к; polyfuse 1 А линии +5 схвата | 1 + 1 | MC
E-041 | Мотор-редуктор NFP-5840-31ZY-DSH, 24 В, i = 670 | 4 | звенья
E-030 | Модуль драйвера DRV8871 | 4 | CH
E-032, E-033, E-034 | Оптрон 6N137; резистор 220 Ом; подтяжка 4,7 кОм | 8 + 8 + 8 | CH
E-035, E-036 | Оптореле RELE КР293КП2Б; резистор 150 Ом | 4 + 4 | CH
E-037 | Реле отключения HF49FD/005-1H11, 5 В, 5 А | 4 | CH
E-038, E-040, E-095 | Модуль датчика тока ACS712-20A; делитель 10 к + 20 к; 0,1 мкФ | 4 + 8 + 4 | CH
E-050 | Реле режима NRP-02-C-05DH, 5 В, SPDT | 16 | CH
E-042 | Модуль энкодера AS5600 с магнитом | 4 | звенья
E-051 | Клеммы разъёма ЛР (винт + гнездо 4 мм) | 20 | LR
E-052, E-053, E-054 | Защита клемм: 100 Ом; BAT54S; 1N4148 | 8 + 8 + 8 | LR
E-060, E-061, E-062 | Расширитель PCF8574; двухцветные светодиоды; резисторы 150 Ом | 1 + 4 + 8 | LR
E-081, E-082 | Провод силовой 18–22 AWG; сигнальный 26–30 AWG | — | —

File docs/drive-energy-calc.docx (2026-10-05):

Энергетический расчёт приводов учебного манипулятора

Выбор мотор-редукторов звеньев M1…M4

МГТУ им. Н.Э. Баумана, группа СМ7-21М · 19.09.2026

# 1 Исходные данные

Массы и длины звеньев приняты по таблице 1 расчётно-пояснительной записки Е.М. Засорина «Разработка привода четвёртого звена учебно-лабораторного манипулятора». Данных по первому звену (поворотной платформе) в записке нет — его собственная масса и момент инерции в расчёте не учтены (см. раздел 7).

Таблица 1 — Массы и длины звеньев

Элемент | Масса m, кг | Длина l, мм
Звено 2 | 3,5 | 540
Звено 3 | 1,5 | 400
Звено 4 | 0,74 | 270
Груз | 0,5 | —

Требования технического задания: тип двигателя — постоянного тока; питание 24 В; управление по положению; угол поворота не более 360°; угловая скорость φ′ = 0,4 рад/с; угловое ускорение φ″ = 1 рад/с²; статическая ошибка по положению не более 3,6°; перерегулирование не более 10 %; время переходного процесса не более 16 с. Коэффициент режима работы принят C_p = 1,3 (тяжёлые условия — возможны перегрузки при неправильном выполнении лабораторных работ). Запас по моменту λ_M = 2.

Ограничения со стороны электроники стенда (утверждены ранее): драйвер DRV8871 с ограничением тока 3,6 А; реле отключения HF49FD/005-1H11 на 5 А; внешний адаптер Mean Well GST220A24-R7B, 24 В, 9,2 А на весь стенд, включая логику и подсветку. Отсюда требование к двигателю: номинальный ток не более 1 А, стопорный не более 3,5 А.

Кинематическая цепь принята в следующем виде. Первое звено (поворот вокруг вертикальной оси): мотор-редуктор → платформа напрямую. Звенья 2…4: мотор-редуктор → зубчато-ременная передача u = 1 → зубчато-ременная передача u = 1 → звено; КПД двух ремённых передач принят η_рем = 0,9 · 0,9 = 0,81.

# 2 Расчёт привода первого звена

Ось вращения первого звена вертикальна, поэтому гравитационный момент на приводе отсутствует и удерживающий момент равен нулю. Нагрузка носит инерционный характер: привод разгоняет всю руку целиком, вследствие чего по требуемому моменту он оказывается наиболее нагруженным из четырёх.

## 2.1 Момент инерции относительно вертикальной оси

Расчёт выполнен для наихудшего положения — рука вытянута горизонтально на максимальный вылет 540 + 400 + 270 = 1210 мм. Звенья приняты однородными стержнями; момент инерции каждого определён по теореме Гюйгенса — Штейнера J = J_c + m·d², где J_c = m·l²/12 — момент инерции стержня относительно собственного центра масс, d — расстояние от центра масс до оси вращения. Для звена 2, вращающегося вокруг своего конца, использована свёрнутая формула J = m·l²/3.

Таблица 2 — Составляющие момента инерции

Элемент | Расчёт | J, кг·м²
Звено 2 | m₂·l₂²/3 = 3,5 · 0,540² / 3 | 0,340
Звено 3 | m₃·l₃²/12 + m₃·0,740² = 1,5 · 0,400²/12 + 1,5 · 0,548 | 0,841
Звено 4 | m₄·l₄²/12 + m₄·1,075² = 0,74 · 0,270²/12 + 0,74 · 1,156 | 0,860
Груз | m_г·1,210² = 0,5 · 1,464 | 0,732
Сумма | J = J₂ + J₃ + J₄ + J_г | 2,773

Для сравнения: момент инерции нагрузки привода четвёртого звена по записке составляет 0,05 кг·м², то есть у первого привода инерция больше в 55 раз.

## 2.2 Требуемый момент

M_m = J · φ″ + M_тр = 2,773 · 1 + 0,3 ≈ 3,1 Н·м (31 кгс·см).

С запасом по методике записки: M_треб = λ_M · M_m = 2 · 3,1 = 6,2 Н·м.

Момент трения в опорном узле и токосъёмном кольце принят оценочно равным 0,3 Н·м (около 10 % от динамической составляющей); достоверного значения нет — параметр требует уточнения. Для шарикового опорного подшипника он был бы на порядок меньше, для скользящей опоры, изготовленной 3D-печатью, — заметно больше.

## 2.3 Требуемая скорость и мощность

Ω = φ′ = 0,4 рад/с = 0,4 · 60 / 2π = 3,82 об/мин.

P = M_m · Ω = 3,1 · 0,4 = 1,24 Вт.

Таким образом, по мощности привод остаётся маломощным — определяющим является момент, а не мощность двигателя.

# 3 Требования к приводу четвёртого звена

По записке максимальный момент на валу четвёртого звена M_m = J·φ″ + M_н = 0,05 · 1 + 2,3 = 2,35 Н·м, из которых 2,3 Н·м — статический момент от веса звена с грузом. С учётом КПД двух ремённых передач требуемый момент на выходном валу мотор-редуктора составляет

M = 2,35 / 0,81 = 2,90 Н·м (29,6 кгс·см) при 3,82 об/мин.

Сравнение с разделом 2 показывает, что требования первого и четвёртого приводов близки (3,1 и 2,9 Н·м на выходном валу), что позволяет применить один тип мотор-редуктора на все четыре звена.

# 4 Проверка кандидатов

Таблица 3 — Сопоставление кандидатов с требованиями первого привода

Параметр | Требуется | JGY-370 «4632», i = 600 | «2480», i = 670
Момент номинальный, Н·м | 3,1 (6,2 с запасом) | 1,56 | 6,87
Момент стопорный, Н·м | — | 2,94 | —
Скорость номинальная, рад/с | 0,40 | 0,79 | 0,94
Ток номинальный, А | ≤ 1,0 | 0,30 | 1,20
Запас по моменту | λ_M = 2 | 0,5 — не проходит | 2,2 — проходит
Цена, ₽ | — | 601 | 2184

Мотор-редуктор JGY-370 не проходит по моменту: требуемые 3,1 Н·м превышают даже его стопорный момент 2,94 Н·м. Причина не в передаточном отношении, а в мощности: максимальная механическая мощность этого семейства на 24 В составляет 1,39 Вт (при i = 340), тогда как для первого привода с запасом λ_M = 2 требуется около 2,5 Вт. Наиболее близкий вариант семейства, i = 1000, даёт 2,60 Н·м при 0,42 рад/с — на 16 % ниже требуемого момента и без какого-либо запаса.

Мотор-редуктор «2480» (червячный, i = 670, двойной вал М8 с фланцем) обеспечивает 6,87 Н·м при 0,94 рад/с и токе 1,2 А, что даёт запас 2,2 по моменту и 2,3 по скорости и укладывается в ограничения драйвера, реле и источника питания.

# 5 Проверка варианта с волновым редуктором

Отдельно проверена возможность сохранить волновой редуктор i₂ = 8 (шариковый, изготовленный 3D-печатью) совместно с мотор-редуктором JGY-370. КПД волновой передачи принят 0,8. Результаты пересчёта на вал первого звена приведены в таблице 4; требуется одновременно 3,1 Н·м и 0,4 рад/с.

Таблица 4 — JGY-370 с волновым редуктором i₂ = 8 на валу первого звена

i редуктора | n номинальная, об/мин | Момент на звене, Н·м | Скорость на звене, рад/с
150 | 30 | 1,26 | 0,393
200 | 22 | 3,33 | 0,288
260 | 18 | 4,21 | 0,236
340 | 15 | 5,65 | 0,196
600 | 7,5 | 9,98 | 0,098
1000 | 4 | 16,64 | 0,052

Ни одно передаточное отношение не удовлетворяет обоим требованиям одновременно: где достаточен момент, не хватает скорости, и наоборот. Волновой редуктор не добавляет мощности, а только перераспределяет её между моментом и оборотами, поэтому недостаток мощности мотор-редуктора им не компенсируется.

При использовании мотор-редуктора «2480» волновая передача не только не нужна, но и противопоказана: момент 6,87 Н·м на её входе дал бы на выходе около 55 Н·м, чего изготовленный 3D-печатью редуктор из ABS не выдержит.

# 6 Выводы

1. Наиболее нагруженным по требуемому моменту является привод первого звена: 3,1 Н·м при 0,4 рад/с (6,2 Н·м с запасом λ_M = 2). Нагрузка носит инерционный характер, удерживающий момент отсутствует.

2. Мотор-редуктор JGY-370 «4632» (24 В, 10 об/мин) не проходит ни по одному из приводов вследствие недостаточной выходной мощности (не более 1,4 Вт).

3. Принят червячный мотор-редуктор «2480» (24 В, i = 670, двойной вал М8 с фланцем), 4 шт.: 6,87 Н·м при 0,94 рад/с и токе 1,2 А. Запас по моменту 2,2, по скорости 2,3. Позиция внесена в базу компонентов под номером E-041.

4. Волновой редуктор i₂ = 8 из состава принятого решения исключён.

5. Червячная передача является самотормозящей: звенья 2…4 удерживаются без тока при обесточивании привода, что дополнительно страхует складную конструкцию манипулятора. Обратной стороной является невозможность провернуть звено вручную при калибровке.
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

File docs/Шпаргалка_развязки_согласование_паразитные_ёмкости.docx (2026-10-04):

Шпаргалка по проектированию печатных плат

Развязки питания · Согласование линий · Паразитные ёмкости · Порядок трассировки и расстановка

Разделы 1–5 — конспект по книге T. C. Hayes, P. Horowitz. Learning the Art of Electronics: A Hands-On Lab Course (Cambridge University Press, 2016), разделы 2N.4, 9N.3–9N.9, 9S.3, 14N.6, 17S.1 и Приложение C; номера страниц — по печатному изданию. Раздел 6 — конспект вебинара Е. Е. Нестерова «Трассировка печатных плат с нуля: как думать инженеру, а не просто рисовать» (Академия программирования
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

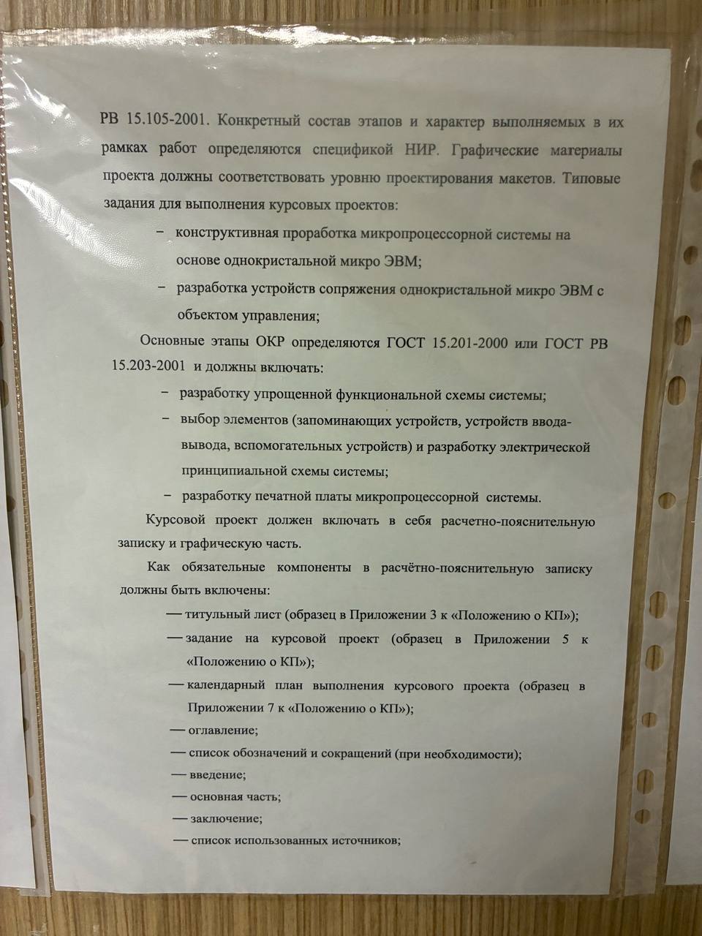
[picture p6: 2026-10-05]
docs/kp-requirements/kp-requirements-2.jpg

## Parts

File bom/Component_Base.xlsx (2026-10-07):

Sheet: Компоненты
ID | Узел | Функция | Тип позиции | Входит в модуль (ID) | Название | Определённость названия | Статус решения | № спорного пункта | Кол-во на канал | Число каналов | Всего | Сторона | Размещение | Ссылка | Цена за шт., ₽ | Есть, шт. | Докупить, шт. | Стоимость докупки, ₽ | Аккуратно! | Источник | Примечание
E-001 | Питание | Блок питания 220 → 24 В (внешний адаптер) | Модуль |  | Mean Well GST220A24-R7B, 24 В, 9,2 А, 221 Вт, штекер DIN 4-pin (R7B) | Выбран | Утверждено |  | 1 | 1 | 1 | Силовая | — | https://www.chipdip.ru/product/gst220a24-r7b-blok-pitaniya-24b-9.2a-221vt-mean-well-9000420376 | 5860 | 0 | 1 | 5860 | Нет | чат 15.09 (утверждено Mikhail) | Вне корпуса, «ноутбучная» схема: 220 В в стенд не заходит. Сетевой шнур C13 покупается отдельно. Прежний кандидат — Ecola LED 200 Вт IP20 (ozon.ru/t/higU70q), судьба уточняется
E-002 | Питание | Кнопка включения питания (коммутирует катушку реле шины 24 В) | Компонент |  | Антивандальная 22 мм, с фиксацией, индикатор 24 В | Выбран | Утверждено |  | 1 | 1 | 1 | Силовая | Панель | https://ozon.ru/t/zLw6TpD | 376 | 0 | 1 | 376 | Нет | чат 15.09 (утверждено Mikhail) | Через контакт — только ток катушки реле (замыкает A2 на GND_P); подсветка 24 В с выхода реле (горит, когда +24 подан). Разъём на PS — XP1 4-конт. (E-092): контакт 1–2, подсветка 3–4. Прежний — тумблер REXANT 15 А (ozon.ru/t/j7BR2sW), судьба уточняется
E-003 | Питание | Предохранитель шины 24 В (после DC-гнезда, до реле) | Компонент |  | Предохранитель флажковый (ATO) 10 А + держатель на провод с крышкой АЭНК 8219 (до 30 А) | Выбран | Утверждено |  | 1 | 1 | 1 | Силовая | Корпус | https://www.chipdip.ru/product/8219-derzhatel-predohranitelya-flazhkovogo-avtoelektronika-8012694315 | 0 | 0 | 1 | 0 | Нет | чат 15.09 (утверждено Mikhail) | Внутри корпуса, врезается в линию +24 между DC-гнездом и реле NRP-15. Цена держателя не заполнена
E-004 | Питание | TVS шины 24 В | Компонент |  | SMCJ26A (однонаправленный, 26 В, 1500 Вт) | Выбран | Утверждено |  | 1 | 1 | 1 | Силовая | PS |  | 0 | 0 | 1 | 0 | Нет | доска + чат 15.09 (утверждено Mikhail) | Параллельно шине +24 после предохранителя; ограничение ниже пределов XL4015E (38 В) и DRV8871 (45 В). SMBJ28A с доски отклонён (R-015)
E-007 | Питание | DC-DC 24 → 5P (силовые 5 В) | Модуль |  | XL4015E, 5 А, регулируемый | Выбран | Утверждено |  | 1 | 1 | 1 | Силовая | PS | https://ozon.ru/t/v0TomWG | 189 | 0 | 1 | 189 | Нет | лист питания | Выставить 5,0 В и зафиксировать; питает ТОЛЬКО +5P: катушки NRP-02 ×16 (~640 мА), оптореле, выходы 6N137. Остров — от E-010
E-008 | Питание | Индикатор «+5P есть» | Компонент |  | Светодиод 2 В (жёлтый по реестру) | Выбран | Утверждено |  | 1 | 1 | 1 | Силовая | Панель | https://ozon.ru/t/1fZdgL1 | 68 | 0 | 1 | 68 | Нет | лист питания | Цвет не фиксирован
E-009 | Питание | Резистор индикатора +5P | Компонент |  | МЛТ-0,25 ±5 %, 150 Ом | Выбран | Утверждено |  | 1 | 1 | 1 | Силовая | PS | https://ozon.ru/t/QWYR5Dy (https://ozon.ru/t/v0TomWG) | 84 | 0 | 1 | 84 | Нет | лист питания | ≈20 мА
E-010 | Питание | Изолированный DC-DC 24 → 5 (логический остров) | Компонент |  | Mornsun VRB2405YMD-10WR3 (24 → 5 В, 10 Вт / 2 А, стабилизированный, изоляция 1,5 кВ) | Выбран | Утверждено |  | 1 | 1 | 1 | Граница | PS |  | 0 | 0 | 1 | 0 | Нет | чат 15.09 (утверждено Mikhail) | Питается от шины +24 (не от XL4015E). Остров ≈0,4 А + линия схвата до 1 А (E-083). Выводы по datasheet Mornsun 2026.03 (YMD, 25,4 × 25,4): 1 Ctrl (свободен), 2 GND, 3 Vin, 4 +Vo, 5 нет вывода, 6 0V; вывод ⌀1,0, отверстие 1,5. B0505S-1W из реестра не используется (R-013)
E-011 | Питание | Источник 3,3 В логики | Компонент |  | Пин 3V3 платы YD-ESP32-S3 (бортовой LDO 5→3,3 В, 1 А) | Выбран | Утверждено |  | 1 | 1 | 1 | Логическая | MC |  | 0 | 0 | 1 | 0 | Нет | чат 15.09 (утверждено Mikhail) | Отдельного компонента нет. Потребители: TCA9548A, подтяжки I2C/RST, подтяжка выхода оптрона KH (<20 мА)
E-012 | Питание | Дроссель фильтра +5P (L1) | Компонент |  | Talema DPO-3.0-22 — тороид 22 мкГн, 3 А, 50 мОм, ⌀14 × 8 мм, выводы 0,5 мм | Выбран | Утверждено |  | 1 | 1 | 1 | Силовая | PS | https://www.chipdip.ru/product/dpo-3-0-22-drossel-pomehopodavlyayuschiy-dpu-22mkgn-talema-8002552890 | 0 | 0 | 1 | 0 | Нет | чат 17.09 (утверждено Mikhail) | LC-фильтр пульсаций после модуля XL4015E вне его петли ОС: L1 + C1 (E-093) + C2 (E-094), f₀ ≈ 1,6 кГц; падение ≈ 50 мВ/А. Footprint L_Toroid_D20_P10.16mm. Цена не заполнена
E-020 | Контроллер | Микроконтроллер | Модуль |  | YD-ESP32-S3 N16R8 DevKit (ESP32-S3-DevKitC-1 clone) | Выбран | Утверждено |  | 1 | 1 | 1 | Логическая | MC | https://ozon.ru/t/Wcg9F9p | 966 | 1 | 0 | 0 | Да | доска + чат 15.09 | Распиновка принята («Аккуратно!»); ПК — родной USB GPIO19/20, запас CH343 GPIO43/44; VIN от изолированных +5; GPIO48 — концевик M1 (предложение)
E-021 | Контроллер | Подтяжки главной шины I2C | Компонент |  | МЛТ-0,25 ±5 %, 4,7 кОм (подтяжка к 3,3 В) | Выбран | Утверждено |  | 2 | 1 | 2 | Логическая | MC |  | 0 | 0 | 2 | 0 | Нет | чат 20.09 (утверждено Mikhail) | На модуле ESP32 подтяжек нет Утверждено 20.09.2026.
E-022 | I2C/датчики | Мультиплексор I2C | Модуль |  | CJMCU-9548 (TCA9548A/PCA9548A) | Выбран | Утверждено |  | 1 | 1 | 1 | Логическая | MC | https://ozon.ru/t/QWYQvBC (https://ozon.ru/t/Wcg9F9p) | 518 | 1 | 0 | 0 | Нет | доска + чат 15.09 | VCC 3,3 В; A2 GND; A0/A1 от ESP32 (GPIO47/38); каналы 0–3
E-023 | I2C/датчики | Подтяжка RST мультиплексора | Компонент |  | МЛТ-0,25 ±5 %, 10 кОм (подтяжка к 3,3 В) | Выбран | Утверждено |  | 1 | 1 | 1 | Логическая | MC |  | 0 | 0 | 1 | 0 | Нет | чат 15.09 | + линия на GPIO42
E-024 | Режим ЛР | Кнопка переключения режима KH | Компонент |  | EKF S-Pro67, 19 мм, с фиксатором, белая подсветка 24 В | Выбран | Утверждено |  | 1 | 1 | 1 | Силовая | Панель | https://ozon.ru/t/3 QXN2ZT (https://ozon.ru/t/3%20QXN2ZT) | 487 | 0 | 1 | 487 | Нет | чат 15.09 (утверждено Mikhail) | Контакт коммутирует +5P на шину KH; подсветка от +24 с PS (XP5, E-018) кабелем напрямую к кнопке, минуя плату LR. Уточнить группу контактов (нужен 1×NO)
E-025 | Режим ЛР | Подтяжка шины KH на землю | Компонент |  | МЛТ-0,25 ±5 %, 1 кОм | Выбран | Утверждено |  | 1 | 1 | 1 | Силовая | MC | https://ozon.ru/t/gmtx6pg | 79 | 0 | 1 | 79 | Нет | лист питания
E-026 | Режим ЛР | Оптореле сигнала KH → ESP32 | Компонент |  | КР293КП2Б (из запаса: в реестре 12 шт., на RELE нужно 4) | Выбран | Утверждено |  | 1 | 1 | 1 | Граница | MC | https://ozon.ru/t/sXzB21l (https://ozon.ru/t/3QXN2ZT) | 73 | 0 | 1 | 73 | Нет | чат 15.09 (утверждено Mikhail) | Статический сигнал — скорость не важна; выход замыкает GPIO41 на GND_L; вход инвертный (в ПО). PC817 отклонён (R-014)
E-027 | Режим ЛР | Резисторы оптореле KH | Компонент |  | МЛТ-0,25 ±5 %, 470 Ом (LED, от шины KH 5 В, ~8 мА) + 10 кОм (подтяжка GPIO41 к 3,3 В) | Выбран | Утверждено |  | 2 | 1 | 2 | Граница | MC |  | 0 | 0 | 2 | 0 | Нет | чат 19.09 (утверждено Mikhail) | Номиналы — предложение под КР293КП2Б (LED ≤10 мА) Утверждено 19.09.2026 в составе силовой части.
E-030 | Канал привода | Драйвер ДПТ | Модуль |  | DRV8871 (модуль, клон Adafruit), 6,5–45 В | Выбран | Утверждено |  | 1 | 4 | 4 | Силовая | CH | https://ozon.ru/t/tPvFr4r | 0 | 4 | 0 | 0 | Нет | чат 19.09 (утверждено Mikhail) | Ждёт мотора: до 3,6 А пик / ~2 А длит. Посадочное место сделать разъёмным Утверждено 19.09.2026 вместе с двигателем E-041 (1,2 А ном.): ток канала известен.
E-031 | Канал привода | Микросхема драйвера на модуле | Внутри модуля | E-030 | DRV8871DDAR | Выбран | Утверждено |  | 1 | 4 | 4 | Силовая | CH |  | 0 | 0 | 0 | 0 | Нет | чат 19.09 (утверждено Mikhail) | Приходит с модулем E-030 Утверждено 19.09.2026 вместе с двигателем E-041 (1,2 А ном.): ток канала известен.
E-032 | Канал привода | Изолятор PWM IN1/IN2 | Компонент |  | 6N137 | Выбран | Утверждено |  | 2 | 4 | 8 | Граница | CH |  | 0 | 0 | 8 | 0 | Нет | чат 14.09 | Замена КР293КП2Б на PWM 20 кГц; выход инвертирующий (в ПО)
E-033 | Канал привода | Резистор LED 6N137 | Компонент |  | МЛТ-0,25 ±5 %, 220 Ом | Выбран | Утверждено |  | 2 | 4 | 8 | Логическая | CH |  | 0 | 0 | 8 | 0 | Нет | чат 14.09 | Общий для ESP32 (3,3 В) и студента (3,3/5 В)
E-034 | Канал привода | Подтяжка выхода 6N137 к +5P | Компонент |  | МЛТ-0,25 ±5 %, 4,7 кОм | Выбран | Утверждено |  | 2 | 4 | 8 | Силовая | CH |  | 0 | 0 | 8 | 0 | Нет | чат 19.09 (утверждено Mikhail) | Утверждено 19.09.2026 в составе силовой части.
E-035 | Канал привода | Оптореле сигнала RELE | Компонент |  | КР293КП2Б | Выбран | Утверждено |  | 1 | 4 | 4 | Граница | CH | https://ozon.ru/t/sXzB21l | 73 | 0 | 4 | 292 | Нет | доска | В реестре 12 шт. → нужно 4 (упаковка по 3)
E-036 | Канал привода | Резистор LED оптореле | Компонент |  | МЛТ-0,25 ±5 %, 150 Ом | Выбран | Утверждено |  | 1 | 4 | 4 | Логическая | CH | https://ozon.ru/t/QWYR5Dy | 84 | 0 | 4 | 336 | Нет | доска | ≤10 мА
E-037 | Канал привода | Реле аварийного отключения питания ДПТ | Компонент |  | HF49FD/005-1H11 (Hongfa, 5 В, 5 А, 30 В DC) | Выбран | Утверждено |  | 1 | 4 | 4 | Силовая | CH | https://ozon.ru/t/ukwD77G (https://ozon.ru/t/sXzB21l) | 108 | 0 | 4 | 432 | Нет | чат 19.09 (утверждено Mikhail) | Годится только при стопорном токе мотора ≤ 5 А; катушка 24 мА через КР293КП2Б Утверждено 19.09.2026 вместе с двигателем E-041 (1,2 А ном.): ток канала известен.
E-038 | Канал привода | Датчик тока | Модуль |  | ACS712-20A (модуль), 100 мВ/А | Выбран | Утверждено |  | 1 | 4 | 4 | Граница | CH | https://ozon.ru/t/1fZ9B9H (https://ozon.ru/t/QWYR5Dy) | 130 | 4 | 0 | 0 | Нет | доска + чат 14.09 | Сигнальная часть — логические +5; измеряемая цепь — силовая
E-039 | Канал привода | Микросхема датчика тока на модуле | Внутри модуля | E-038 | ACS712ELCTR-20A | Выбран | Утверждено |  | 1 | 4 | 4 | Граница | CH |  | 0 | 0 | 0 | 0 | Нет | модуль | Приходит с модулем E-038
E-040 | Канал привода | Согласование выхода ACS712 с ADC ESP32 | Компонент |  | С2-23-0,25 ±1 %, делитель 10 кОм + 20 кОм | Выбран | Утверждено |  | 2 | 4 | 8 | Логическая | CH |  | 0 | 0 | 8 | 0 | Нет | чат 19.09 (утверждено Mikhail) | 0–5 В → 0–3,3 В; не утверждено Утверждено 19.09.2026 вместе с силовой частью.
E-041 | Канал привода | Двигатель ДПТ 24 В | Компонент |  | Червячный мотор-редуктор NFP-5840-31ZY-DSH («2480»), 24 В, i = 670, двойной вал Ø8 мм, с фланцем | Выбран | Утверждено |  | 1 | 4 | 4 | Силовая | Звено | https://market.yandex.ru/cc/B6zFNi | 2184 | 0 | 4 | 8736 | Да | чат 19.09 (утверждено Mikhail) | Червячный, самотормозящий. Паспорт класса (5840-31ZY, 24 В, i=670): 12 об/мин х.х., 9 об/мин и 70 кгс·см номинал, ток ≤1,2 А. Расчёт: M1 (вертикальная ось, J=2,77 кг·м² при вылете 1,21 м с грузом 0,5 кг) требует 3,1 Н·м при ε=1 рад/с² — запас ×2,2; звено 4 требует 2,35 Н·м, после двух ремней получаем 5,6 Н·м — запас ×2,4. Волновой редуктор i=8 НЕ ставится: дал бы 55 Н·м на печатном ABS-редукторе. Проверить у продавца стопорный ток (паспортные ≤1,6 А сомнительны) и что вал М8 — гладкий Ø8, а не резьба: под магнит AS5600 нужен ровный торец. Определяет (2), (6), (7), (16): по трём моторам M2…M4 токосъёмное кольцо ≥ 5 А. Отклонён FGA-43246000-G149 (4,5 А ном., ~20 А стоп) Модель по каталогу nfpshop.com (NFP-5840-31ZY-DSH).
E-042 | I2C/датчики | Датчик положения звена | Модуль |  | AS5600 (модуль) | Выбран | Утверждено |  | 1 | 4 | 4 | Логическая | Звено |  | 0 | 4 | 0 | 0 | Нет | доска | Питание — логические +5/3,3 В (остров), не +5P; M2…M4 — через кольцо
E-043 | I2C/датчики | Микросхема энкодера на модуле | Внутри модуля | E-042 | AS5600-ASOM | Выбран | Утверждено |  | 1 | 4 | 4 | Логическая | Звено |  | 0 | 0 | 0 | 0 | Нет | модуль | Приходит с модулем E-042
E-044 | I2C/датчики | Подтяжки I2C на модуле AS5600 | Внутри модуля | E-042 | 10 кОм (типично для модулей) | Кандидат | Уточняется |  | 2 | 4 | 8 | Логическая | Звено |  | 0 | 0 | 0 | 0 | Нет | чат 15.09 | Проверить наличие на конкретном модуле; должны быть на стороне энкодера
E-050 | Режим ЛР | Реле переключения режима (IN1, IN2, SDA, SCL) | Компонент |  | NRP-02-C-05DH, 5 В, SPDT, 3 А | Выбран | Утверждено |  | 4 | 4 | 16 | Граница | CH | https://www.chipdip.ru/product/nrp-02-c-05dh-rele-1-pereklyuch-5vdc-3a-125vac-spdt-na-ncr-9000276611 | 51 | 0 | 16 | 816 | Нет | доска + ChipDip | Катушки от шины KH (+5P), ~40 мА каждая; сторона — граница: катушки от +5P, контакты в логических цепях
E-098 | Режим ЛР | Разъём сигнальный 5 контактов | Компонент |  | JST B5B-XH-A (LF)(SN), вилка прямая на плату, XH, 2,5 мм, 5 контактов, 3 А | Выбран | Утверждено |  | 9 | 1 | 9 | Логическая | LR |  | 0 | 0 | 9 | 0 | Нет | чат 06.10 (утверждено Mikhail) | LR X1…X8 (8 шт.) и CH X2 (1 шт.); позиция клемм ZP-001 (E-051) исключена 06.10.2026
E-052 | Режим ЛР | Защита SDA/SCL разъёма ЛР — последовательный резистор | Компонент |  | МЛТ-0,25 ±5 %, 100 Ом | Выбран | Утверждено |  | 2 | 4 | 8 | Логическая | LR |  | 0 | 0 | 8 | 0 | Да | чат 19.09 (утверждено Mikhail) | Решение «добавить защиту» принято, номиналы — предложение Утверждено 19.09.2026 вместе с разъёмом ЛР.
E-053 | Режим ЛР | Защита SDA/SCL разъёма ЛР — ограничитель | Компонент |  | BAT54S (сборка на 3,3 В и GND) | Выбран | Утверждено |  | 2 | 4 | 8 | Логическая | LR |  | 0 | 0 | 8 | 0 | Да | чат 19.09 (утверждено Mikhail) | Утверждено 19.09.2026 вместе с разъёмом ЛР.
E-054 | Режим ЛР | Защита IN1/IN2 разъёма ЛР — встречный диод | Компонент |  | 1N4148 или аналог | Выбран | Утверждено |  | 2 | 4 | 8 | Логическая | LR |  | 0 | 0 | 8 | 0 | Да | чат 19.09 (утверждено Mikhail) | От отрицательного напряжения / переполюсовки на LED 6N137 Утверждено 19.09.2026 вместе с разъёмом ЛР.
E-060 | Индикация | Расширитель портов для индикации | Компонент |  | PCF8574 (DIP или модуль) | Выбран | Утверждено |  | 1 | 1 | 1 | Логическая | LR |  | 0 | 0 | 1 | 0 | Да | чат 20.09 (утверждено Mikhail) | Принцип «через мультиплексор» утверждён; PCF8574 — предложение. 8 выходов = 4 двухцветных LED без запаса Утверждено 20.09.2026. Остаётся «Аккуратно!»: 8 выходов = ровно 4 двухцветных светодиода без запаса; под индикацию режима или аварии понадобится PCF8575 либо второй PCF8574.
E-061 | Индикация | Индикатор состояния звена | Компонент |  | Двухцветный LED зелёный/красный, 3 вывода | Только функция | Утверждено |  | 1 | 4 | 4 | Логическая | LR |  | 0 | 0 | 4 | 0 | Да | чат 15.09 | Логика свечения — в требования к ПО
E-062 | Индикация | Резисторы индикаторов звеньев | Компонент |  | МЛТ-0,25 ±5 %, 150 Ом | Выбран | Утверждено |  | 2 | 4 | 8 | Логическая | LR |  | 0 | 0 | 8 | 0 | Нет | чат 20.09 (утверждено Mikhail) | Аноды к +3,3, катоды на PCF8574 (зажигание нулём) Утверждено 20.09.2026.
E-070 | Схват | Соединение съёмного схвата | Модуль |  | Магнитный pogo-разъём 2-pin, шаг 2,8 мм | Кандидат | Уточняется | (14) | 4 | 1 | 4 | Граница | Схват | https://market.yandex.ru/cc/AwZszU | 150 | 0 | 4 | 600 | Нет | реестр | Нужно 6 + 1 резерв контактов → 4 пары; проверить ток пина для +24 / 2 А
E-071 | Схват | Электроника схвата (контроллер, драйвер M5, датчики) | Компонент |  |  | Только функция | Уточняется | (13) | 1 | 1 | 1 | — | GR |  | 0 | 0 | 1 | 0 | Нет | ТЗ v0.2 | Отдельное ТЗ; датчики схвата — внутри, по UART
E-072 | Схват | Двигатель схвата M5 | Компонент |  | Коллекторный ДПТ 24 В, ≤ 2 А | Только функция | Уточняется | (13) | 1 | 1 | 1 | Силовая | Схват |  | 0 | 0 | 1 | 0 | Нет | чат 14.09
E-073 | Схват | Защита линии ESP-RX от 5-вольтового передатчика | Компонент |  | С2-23-0,25 ±1 %, делитель 10 кОм + 20 кОм на линии ESP-RX (5 В → 3,3 В) | Выбран | Утверждено |  | 1 | 1 | 1 | Логическая | MC |  | 0 | 0 | 1 | 0 | Нет | чат 20.09 (утверждено Mikhail) | Контроллер схвата не выбран (3,3 или 5 В) Утверждено 20.09.2026: на разъём схвата выводится +5 В логики, контроллер схвата может оказаться 5-вольтовым, поэтому защита входа ESP32 обязательна независимо от его выбора. Номиналы приняты как у E-040; при переходе схвата на 3,3 В делитель можно заменить перемычкой.
E-080 | Кольцо/провода | Токосъёмное кольцо платформы | Компонент |  |  | Только функция | Уточняется | (16) | 1 | 1 | 1 | Граница | Корпус |  | 0 | 0 | 1 | 0 | Нет | доска | Дорожки: 6 силовых (M2…M4, ток по мотору) + I2C и +5/GND энкодеров + 6–7 схвата; силовые и логические дорожки раздельно
E-081 | Кольцо/провода | Провод силовой | Компонент |  | 20–22 AWG | Выбран | Утверждено |  | 1 | 1 | 1 | Силовая | — |  | 0 | 0 | 1 | 0 | Нет | реестр | Бухта; Участок DC-гнездо → предохранитель → реле NRP-15 (полный ток 9,2 А) — 18 AWG (утверждено 16.09)
E-082 | Кольцо/провода | Провод сигнальный | Компонент |  | 30 AWG | Выбран | Утверждено |  | 1 | 1 | 1 | Логическая | — |  | 0 | 0 | 1 | 0 | Нет | реестр | I2C, UART; для +5 логики к схвату лучше 26–28 AWG
E-013 | Питание | Реле шины 24 В (включение питания стенда) | Компонент |  | NRP-15-C-24D (NCR), катушка 24 В DC 619 Ом / 39 мА / 0,93 Вт, контакт 1C: 20 А 28 В DC (30 А — только 1A) | Выбран | Утверждено |  | 1 | 1 | 1 | Силовая | PS | https://www.chipdip.ru/product/nrp-15-c-24d | 0 | 0 | 1 | 0 | Нет | чат 15.09 (утверждено Mikhail) | Контакт COM–NO рвёт шину +24 после предохранителя; A1 — +24V_IN постоянно, A2 — на GND_P через контакт кнопки E-002 (XP1). NC не используется. По datasheet NCR NRP15 (ncr.hk): 1C — 20 А/28 В DC. Footprint Relay_NRP-15_1C — вид снизу datasheet зеркалирован, перед пайкой прозвонить COM–NC обесточенного реле
E-014 | Питание | DC-гнездо питания на корпусе (вход 24 В от адаптера) | Компонент |  | Kycon KPJX-PM-4S — панельное гнездо 4-pin power mini-DIN, 7,5 А/контакт, 48 В; ответная часть к штекеру R7B адаптера | Выбран | Утверждено |  | 1 | 1 | 1 | Силовая | Панель | https://www.chipdip.ru/product/kpjx-pm-4s-dc-power-connectors-4-pn-panel-mt-mini-din-kycon-8005303752 | 790 | 0 | 1 | 790 | Нет | чат 16.09 (утверждено Mikhail) | Кабель адаптера несъёмный, штекер R7B вставляется напрямую. +V и GND — по два контакта на полюс (распиновку сверить с PDF Kycon и спецификацией Mean Well). Срок поставки ChipDip 6–7 недель; проверить тип выводов (под пайку провода)
E-015 | Питание | Диод параллельно катушке реле E-013 | Компонент |  | 1N4007 (катодом к +24) | Выбран | Утверждено |  | 1 | 1 | 1 | Силовая | PS |  | 0 | 0 | 1 | 0 | Нет | чат 19.09 (утверждено Mikhail) | Гасит выброс катушки при размыкании, бережёт контакт кнопки Утверждено 19.09.2026 в составе силовой части.
E-083 | Схват | Защита линии +5 схвата (в основании) | Компонент |  | Самовосстанавливающийся предохранитель (polyfuse) Bourns MF-R110 (Ihold 1,1 А, Itrip 2,2 А, 30 В) | Выбран | Утверждено |  | 1 | 1 | 1 | Логическая | MC |  | 0 | 0 | 1 | 0 | Нет | чат 15.09 (утверждено Mikhail) | Функция и порог ~1 А утверждены; модель — Bourns MF-R110 (утверждено Mikhail 05.10.2026: «MF-R100» в серии Bourns MF-R нет, ближайший с Ihold ≥ 1 А — MF-R110; datasheet MF-R rev. Z 06/13). Требование внесено в ТЗ схвата v0.3
E-090 | Канал привода | Концевой выключатель M1 — опорная метка нуля поворота платформы | Компонент |  | Микропереключатель с рычагом без ролика (тип KW11-3Z / KW12-3), SPDT, использовать NC-контакт; упаковка 5 шт. | Выбран | Утверждено |  | 1 | 1 | 1 | Логическая | Основание | https://ozon.ru/t/CrIV1po | 26 | 0 | 1 | 26 | Нет | чат 16.09 (утверждено Mikhail) | Только на M1 (в основании, без кольца). Служит нулём: кулачок на платформе нажимает в опорном положении; пределы поворота — программные. На M2…M4 концевиков нет — ограничение по углу AS5600 и току. COM → GND_L, NC → GPIO ESP32
E-091 | Канал привода | Обвязка концевика M1 | Компонент |  | МЛТ-0,25 ±5 %, 10 кОм (подтяжка к 3,3 В) + конденсатор керамический 0,1 мкФ 50 В X7R (фильтр дребезга) | Выбран | Утверждено |  | 2 | 1 | 2 | Логическая | MC |  | 0 | 0 | 2 | 0 | Нет | чат 20.09 (утверждено Mikhail) | Вход ESP32 — GPIO48 из резерва (предложение, «Аккуратно!» в распиновке); обработка по прерыванию Утверждено 20.09.2026; GPIO48 остаётся пометкой «Аккуратно!» в распиновке, к выбору компонента не относится.
E-016 | Питание | Сетевой шнур адаптера (Schuko — IEC C13) | Компонент |  | REXANT 11-1121: вилка CEE 7/7 угловая — IEC 320 C13, 3×0,75 мм², 1,8 м (альтернатива: Power Cube 3×1,0 мм², 16 А) | Выбран | Утверждено |  | 1 | 1 | 1 | Силовая | — | https://www.chipdip.ru/product/11-1121-shnur-setevoy-vilka-uglovaya-see-7-7-schuko-rexant-8518334503 | 0 | 0 | 1 | 0 | Нет | чат 16.09 (утверждено Mikhail) | Вход адаптера GST220A — C14, шнур в комплект не входит; ток от сети ~1 А. Цена не заполнена; подойдёт любой имеющийся шнур от монитора/ПК
E-017 | Питание | Клеммник силовых линий 24 В на плате PS (вход J1, выходы J3…J7) | Компонент |  | DG301-5.0-02P-12 (KLS2-301-5.00-02P-2S), Degson — клеммник винтовой на плату, 2 контакта, шаг 5,0 мм, прямой, 15 А / 300 В (UL), провод 0,75–1,5 мм² (22–14 AWG) | Выбран | Утверждено |  | 6 | 1 | 6 | Силовая | PS | https://www.chipdip.ru/product/dg301-5.0-02p-12-kls2-301-5.00-02p-2s-klemmnik-degson-9000110359 | 0 | 0 | 6 | 0 | Нет | чат 17.09 (утверждено Mikhail) | XT1 (вход, 18 AWG), XT2…XT6 (выходы +24, 20–22 AWG). По чертежу Degson 200102539: корпус 5,0×N × 7,6 × 10 мм, вывод ⌀1,0, отверстие 1,2 (в footprint 1,3), винт M2.5, момент 0,29 Н·м. Ответная часть не нужна; полярность — шёлкографией; стыкуются в ряд
E-018 | Питание | Разъём сигнальный малого тока на PS (LED панели XP4, питание подсветки KH XP5) | Компонент |  | JST B2B-XH-A (LF)(SN) — вилка прямая на плату, серия XH, 2,5 мм, 2 контакта, 3 А | Выбран | Утверждено |  | 2 | 1 | 2 | Силовая | PS | https://www.chipdip.ru/product/b2b-xh-a-lf-sn-razem-shtyrevoy-na-platu-2.5-mm-2-jst-9000015961 | 0 | 0 | 2 | 0 | Нет | чат 17.09 (утверждено Mikhail) | XP4 (LED «+5P есть» E-008), XP5 (+24 на подсветку кнопки KH E-024, кабель к кнопке). Ответная часть на кабель: корпус XHP-2 + контакты SXH-001T-P0.6 ×2 — докупить к каждому разъёму. Тот же тип — на LR и MC
E-019 | Питание | Разъём питания логики PS → MC (+5P XP2, +5 остров XP3) | Компонент |  | JST B2P-VH — вилка прямая на плату, серия VH, 3,96 мм, 2 контакта, 10 А | Выбран | Утверждено |  | 2 | 1 | 2 | Граница | PS | https://www.chipdip.ru/product/b2p-vh | 0 | 0 | 2 | 0 | Нет | чат 17.09 (утверждено Mikhail) | XP2 (+5P → MC), XP3 (+5 остров → MC, с выхода U2). Ответная часть на кабель: корпус VHR-2N + контакты SVH-21T-P1.1 ×2 (18–22 AWG) — докупить к каждому разъёму
E-092 | Питание | Разъём кнопки питания на PS (XP1: контакт катушки + подсветка) | Компонент |  | JST B4B-XH-A (LF)(SN) — вилка прямая на плату, серия XH, 2,5 мм, 4 контакта, 3 А | Выбран | Утверждено |  | 5 | 1 | 1 | Силовая | PS | https://www.chipdip.ru/product/b4b-xh-a-lf-sn-razem-shtyrevoy-4-kontakta-2.5mm-na-jst-9000628021 | 0 | 0 | 1 | 0 | Нет | чат 17.09 (утверждено Mikhail) | PS X2 (кнопка питания), MC X1 и X2, MC X10, LR X9 — вилка на 4 контакта; PS X2 и MC X2 переключены с E-018 06.10.2026
E-093 | Питание | Конденсатор фильтра +5P (C1) | Компонент |  | Электролитический 470 мкФ 16 В, 105 °C, low ESR, ⌀8 мм, шаг 3,5 мм (любой производитель) | Только функция | Утверждено |  | 1 | 1 | 1 | Силовая | PS |  | 0 | 0 | 1 | 0 | Нет | чат 17.09 (утверждено Mikhail) | Footprint CP_Radial_D8.0mm_P3.50mm; «+» — вывод 1. Конкретную марку выбрать при закупке
E-094 | Питание | Конденсатор фильтра +5P (C2) | Компонент |  | Керамический 0,1 мкФ 50 В X7R, выводной, шаг 5 мм | Только функция | Утверждено |  | 1 | 1 | 1 | Силовая | PS |  | 0 | 0 | 1 | 0 | Нет | чат 17.09 (утверждено Mikhail) | Footprint C_Disc_P5.00mm. Конкретную марку выбрать при закупке
E-095 | Канал привода | Конденсатор фильтра сигнала CURR перед АЦП | Компонент |  | Керамический 0,1 мкФ 50 В X7R, выводной, шаг 5 мм | Только функция | Утверждено |  | 1 | 4 | 4 | Логическая | CH |  | 0 | 0 | 4 | 0 | Нет | чат 29.09 (утверждено Mikhail) | Footprint C_Disc_P5.00mm. Ставится в среднюю точку делителя R6/R7 (за резистором 10 кОм): у ACS712 допустимая ёмкость нагрузки не более 10 нФ, поэтому прямо на выход датчика конденсатор ставить нельзя. Снижает выходное сопротивление источника для АЦП ESP32 (6,7 кОм) и усредняет ШИМ 20 кГц: RC около 0,67 мс, полоса около 240 Гц
E-096 | Контроллер | Разъём межплатного шлейфа 2×6 | Компонент |  | Вилка IDC BH-12 (DS1013-12SIB), на плату, 2×6, шаг 2,54 мм, с ключом, 1 А | Выбран | Утверждено |  | 5 | 1 | 5 | Логическая | MC |  | 0 | 0 | 5 | 0 | Нет | чат 05.10 (утверждено Mikhail) | MC X6…X9 (4 шт.) и CH X1 (1 шт.); в схемах поле BaseID не проставлено
E-097 | Контроллер | Гнёзда под модуль контроллера | Компонент |  | Гнездо PBS-22 (DS1023-1×22), однорядное, 22 контакта, шаг 2,54 мм | Выбран | Утверждено |  | 2 | 1 | 2 | Логическая | MC |  | 0 | 0 | 2 | 0 | Нет | чат 05.10 (утверждено Mikhail) | MC XS1, XS2 — пара гнёзд под модуль; в схемах поле BaseID не проставлено

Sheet: Модули
ID | Название модуля | Узел | Статус | Что уже на плате (см. «Внутри модуля») | Что нужно рядом на нашей плате | Нужно, шт. | Есть, шт. | Докупить | Ссылка
E-001 | Mean Well GST220A24-R7B (внешний адаптер 24 В, 221 Вт) | Питание | Утверждено | Сетевой вход C14, защиты КЗ/перегрузки/перенапряжения/перегрева, индикатор, штекер DIN 4-pin | DC-гнездо E-014, предохранитель 10 А E-003, реле E-013 + диод E-015, кнопка E-002 | 1 | 0 | 1 | https://www.chipdip.ru/product/gst220a24-r7b-blok-pitaniya-24b-9.2a-221vt-mean-well-9000420376
E-007 | XL4015E 24→5P | Питание | Утверждено | XL4015E, дроссель, диод, подстроечник | фильтр +5P, индикатор | 1 | 0 | 1 | https://ozon.ru/t/v0TomWG
E-020 | YD-ESP32-S3 DevKit | Контроллер | Утверждено | ESP32-S3-WROOM N16R8, LDO 3,3 В, CH343, USB-C ×2, кнопки BOOT/RST | подтяжки I2C, гребёнки | 1 | 1 | 0 | https://ozon.ru/t/Wcg9F9p
E-022 | CJMCU-9548 (TCA9548A) | I2C/датчики | Утверждено | TCA9548A, подтяжки адресных входов | 10 кОм на RST, питание 3,3 В | 1 | 1 | 0 | https://ozon.ru/t/QWYQvBC
E-030 | DRV8871 модуль | Канал привода | Уточняется | DRV8871, конденсатор VM, клеммники | 6N137 ×2 с резисторами и подтяжками, реле HF49FD | 4 | 4 | 0 | https://ozon.ru/t/tPvFr4r
E-038 | ACS712-20A модуль | Канал привода | Утверждено | ACS712ELCTR-20A, фильтр, клеммник | делитель 10к/20к на выход (предложение) | 4 | 4 | 0 | https://ozon.ru/t/1fZ9B9H
E-042 | AS5600 модуль | I2C/датчики | Утверждено | AS5600, подтяжки I2C (проверить), магнит | реле NRP-02 ×2 на SDA/SCL, питание с острова | 4 | 4 | 0
E-070 | Pogo магнитный 2-pin | Схват | Уточняется | — | 4 пары на 7 контактов | 4 | 0 | 4 | https://market.yandex.ru/cc/AwZszU
Количества подтягиваются с листа «Компоненты» по ID (формулы INDEX/MATCH). Состав «что на плате» — текст; детализация — строки типа «Внутри модуля» на листе «Компоненты».

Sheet: Отклонено
ID | Узел | Что было предложено / стояло в реестре | Чем заменено | Причина | Дата решения
R-001 | Питание | Ступени DC-DC 24→12 В и 12→5 В (LM2596 → LM2672) | XL4015E 24→5P напрямую | DRV8871 питается от 24 В, 12 В не нужны | 14.09.2026
R-002 | Режим ЛР | Второй B0505S-1W в цепи KH + делитель 2×500 Ом → ESP-KH 2,5 В | Оптрон (PC817 — предложение) | Уровень 2,5 В на границе порога ESP32; изолированный DC-DC ради одного сигнала избыточен | 14.09.2026
R-003 | Канал привода | КР293КП2Б на входах IN1/IN2 драйвера | 6N137 | Время переключения ~1 мс не пропускает PWM 20 кГц | 14.09.2026
R-004 | Индикация | Красный LED + 50 Ом напрямую с GPIO ESP32 (ESP-Mx-VD ×4) | Двухцветные LED через PCF8574 | 50 Ом → 26 мА с GPIO (выше нормы); экономия выводов | 14–15.09.2026
R-005 | Режим ЛР | Тумблер REXANT как переключатель KH | Кнопка с фиксацией и подсветкой 24 В | Решение по эргономике (фото) | 14.09.2026
R-006 | Схват | Собственный изолированный DC-DC в схвате из +24 В для логики | Логика схвата от изолированных +5 основания | Потребовал бы изолятора UART в основании | 14.09.2026
R-007 | Схват | CAN / I2C как интерфейс до схвата | UART (RX/TX, 3,3 В TTL) | Проще; 6 проводов | 14.09.2026
R-008 | Канал привода | Канал привода M5 в основании (5-й DRV8871, ACS712, канал мультиплексора) | Электроника M5 в съёмном схвате, данные по UART | Схват — съёмный модуль с собственной электроникой | 14.09.2026
R-009 | Канал привода | Оптроны 4-выводные ×20 на каждый PWM (схема курсового проекта) | 6N137 ×8 + КР293КП2Б ×4 | Зачёркнуто на доске; заменено рукописной схемой | доска
R-010 | I2C/датчики | Питание TCA9548A от +5 В | 3,3 В | Порог входов 0,7·VCC = 3,5 В — не видит уровни ESP32 | 15.09.2026
R-011 | Контроллер | USB через мост CH343 (UART0) как основной канал к ПК | Родной USB ESP32-S3 (GPIO19/20) | Решение Mikhail; CH343 — запасной вариант | 15.09.2026
R-012 | Канал привода | Мотор StepperOnline FGA-43246000-G149 как утверждённый | Двигатель не определён (кандидат сохранён) | Под 4,5 А ном. / ~20 А стоп. не проходят DRV8871, HF49FD 5 А, БП 200 Вт | 14.09.2026
R-013 | Питание | B0505S-1W ×4 для питания острова | Один изолированный модуль 2–3 Вт (предложение) | Бюджет острова 280–400 мА; параллелить 1-ваттные нецелесообразно | 14.09.2026
R-014 | Режим ЛР | PC817 как оптрон сигнала KH → ESP32 (E-026) | КР293КП2Б из запаса (реестр 12 шт., нужно 4) | Сигнал статический, скорость не нужна; КР293КП2Б уже куплены — новая позиция не требуется | 15.09.2026
R-015 | Питание | SMBJ28A как TVS шины 24 В (с доски) | SMCJ26A | Ограничение SMBJ28A (~45 В) выше предела XL4015E (38 В); SMCJ26A мощнее и ограничивает ниже | 15.09.2026
R-016 | Питание | Отдельный индикатор «+24 есть» на панели: светодиод E-005 + резистор 1 кОм E-006 (R1, XP4 на PS) | Встроенная подсветка 24 В кнопки питания E-002 через 4-конт. разъём XP1 (E-092), питание с выхода реле | Кнопка уже содержит индикатор 24 В; отдельный светодиод и резистор дублируют его | 17.09.2026
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

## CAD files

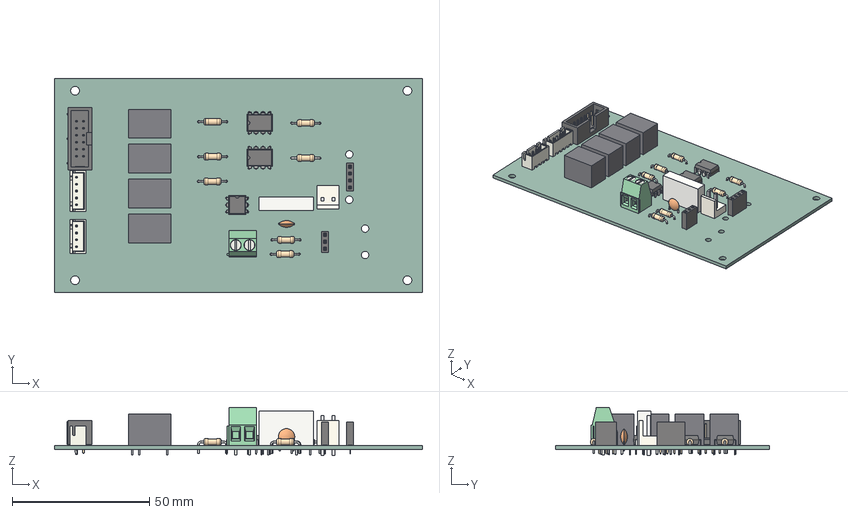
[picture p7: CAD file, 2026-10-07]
boards/CH/CH.step
134.0 x 78.0 x 17.5 mm
R_Axial_DIN0207_L63mm_D25mm_P1016mm_Horizontal x 7
IDC_Header_2x06_P254mm_Vertical
pin1 x 6
pin2 x 6
pin3 x 5
pin4 x 5
pin5 x 4
pin6 x 4
JST_B4B_XH_A
C_Disc_D60mm_W25mm_P500mm
PinSocket_1x03_P2.54mm_Vertical
DIP-8_W7.62mm x 2
PinSocket_1x04_P2.54mm_Vertical
JST_B5B_XH_A
TerminalBlock_Phoenix_MKDS-1,5-2_1x02_P5.00mm_Horizontal
DIP-6_W7.62mm
CH_PCB

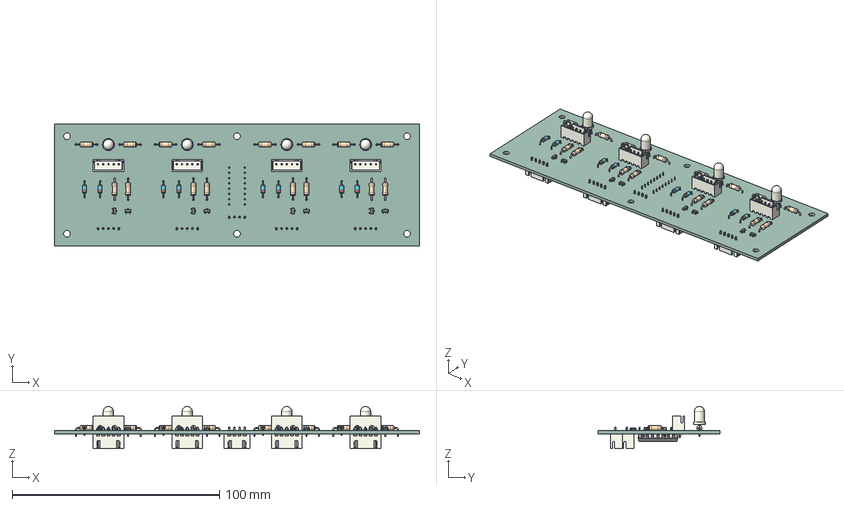
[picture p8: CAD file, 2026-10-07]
boards/LR/LR.step
176.0 x 59.0 x 20.3 mm
JST_B5B_XH_A x 8
D_DO-35_SOD27_P7.62mm_Horizontal x 8
R_Axial_DIN0207_L63mm_D25mm_P1016mm_Horizontal x 16
LED_D5.0mm-3 x 4
SOT-23 x 8
JST_B4B_XH_A
DIP-16_W7.62mm
LR_PCB

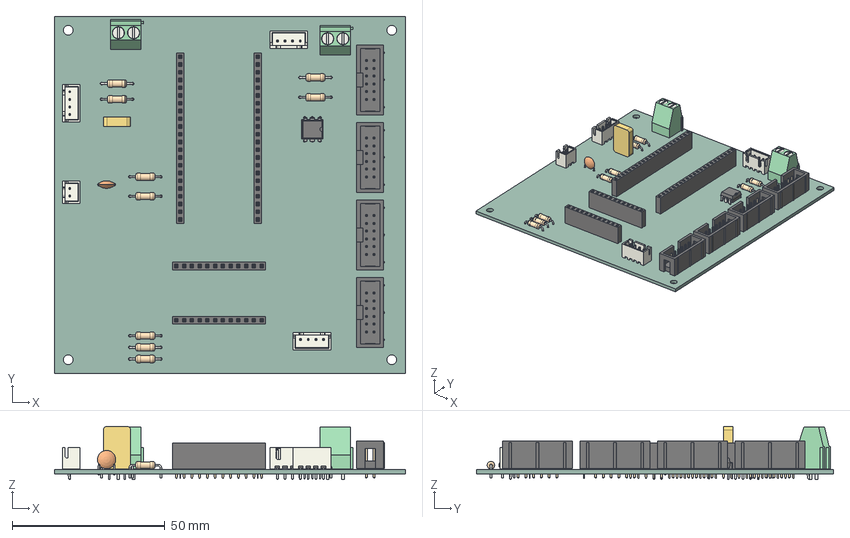
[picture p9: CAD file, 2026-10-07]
boards/MC/MC.step
115.0 x 117.0 x 17.5 mm
R_Axial_DIN0207_L63mm_D25mm_P1016mm_Horizontal x 9
pin1
pin2
JST_B4B_XH_A x 3
DIP-6_W7.62mm
IDC_Header_2x06_P254mm_Vertical x 4
TerminalBlock_Phoenix_MKDS-1,5-2_1x02_P5.00mm_Horizontal x 2
JST_B2B_XH_A
C_Disc_D60mm_W25mm_P500mm
PinSocket_1x12_P2.54mm_Vertical x 2
PinSocket_1x22_P2.54mm_Vertical x 2
MC_PCB

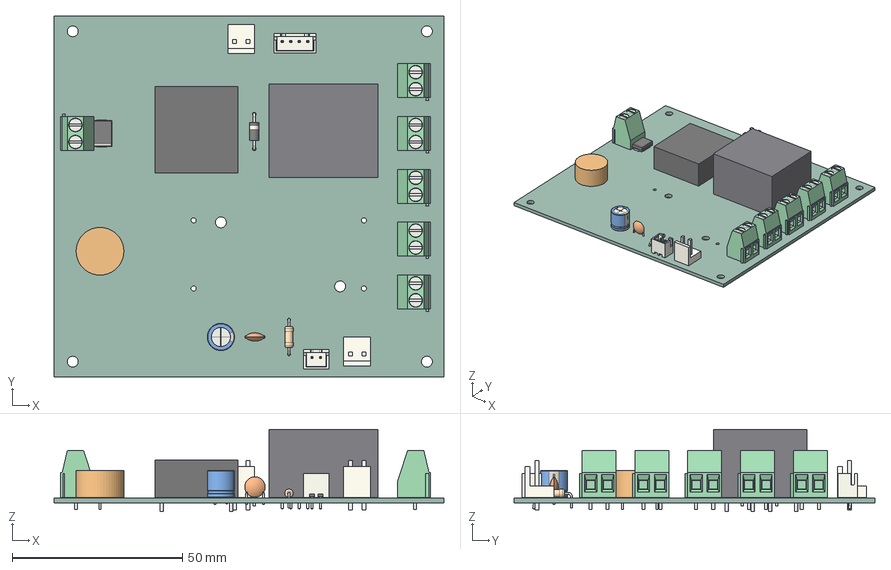
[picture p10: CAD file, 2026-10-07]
boards/PS/PS.step
114.5 x 106.0 x 24.1 mm
D_DO-41_SOD81_P10.16mm_Horizontal
TerminalBlock_Phoenix_MKDS-1,5-2_1x02_P5.00mm_Horizontal x 6
pin1 x 4
pin2 x 4
pin3
pin4
pin5
JST_B2B_XH_A
CP_Radial_D80mm_P350mm
C_Disc_D60mm_W25mm_P500mm
D_SMC
JST_B4B_XH_A
R_Axial_DIN0207_L63mm_D25mm_P1016mm_Horizontal
PS_PCB

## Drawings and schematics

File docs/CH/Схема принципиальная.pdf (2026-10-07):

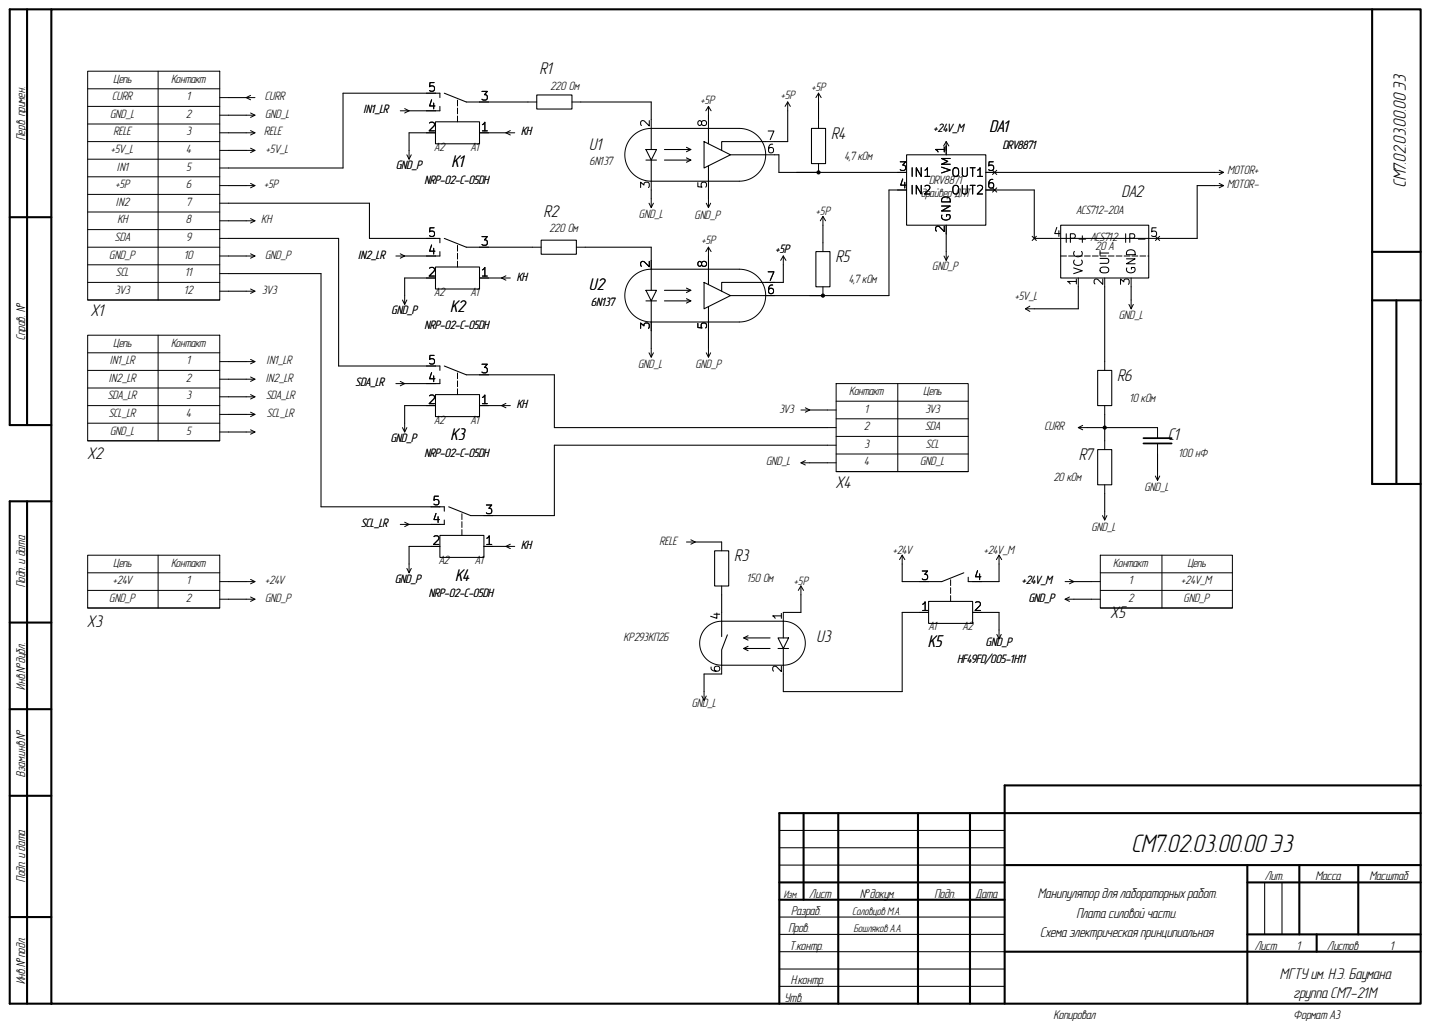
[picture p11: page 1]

Цепь
CURR
GND_L

RELE | Контакт 123456789

Перв. примен. Подп. и дата Подп. и дата

+5V_L
IN1
+5P
IN2
KH
SDA
GND_P | 10

SCL | 11
3V3 | 12

IN2_LR | Контакт 12345

IN1_LR

Контакт 1234 | 3V3

SDA_LR
SCL_LR

SCL

Инв.N°дубл. Инв.N°подл.

Изм. | Лист | N°докум. | Подп. | Дата
Разраб. | | Соловцов М.А.
Пров. | | Бошляков А.А.
Т.контр.

Манипулятор для лабораторных работ.

Н.контр.

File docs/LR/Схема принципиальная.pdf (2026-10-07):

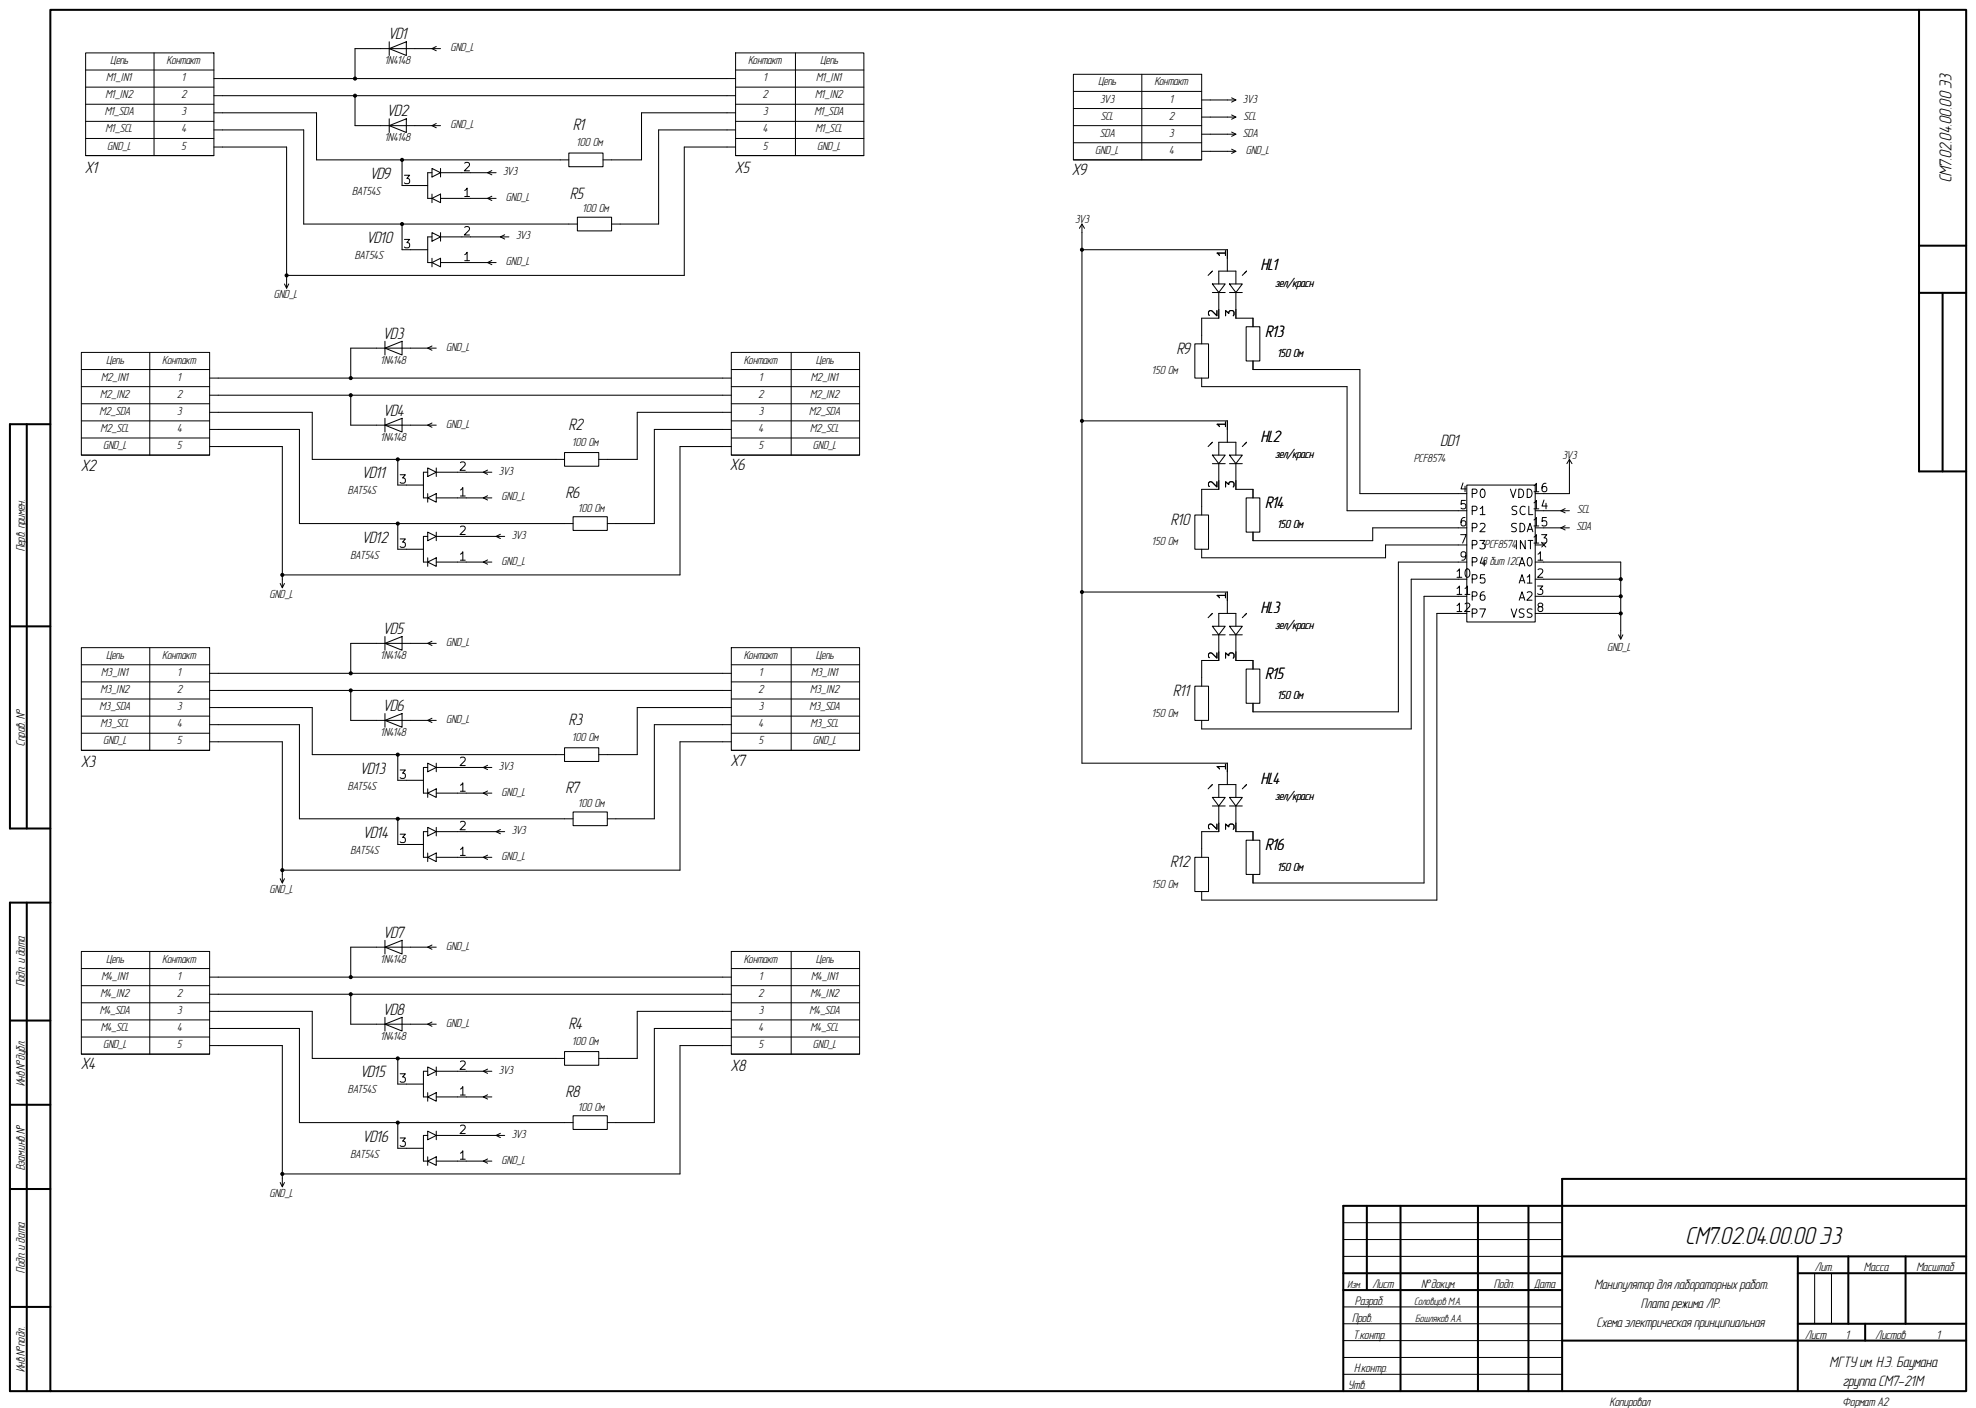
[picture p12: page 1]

Цепь

3V3 | Контакт 1234

SCL
SDA
GND_L

Перв. примен. Подп. и дата Подп. и дата

Инв.N°дубл. Инв.N°подл.

Изм. | Лист | N°докум. | Подп. | Дата
Разраб. | | Соловцов М.А.
Пров. | | Бошляков А.А.
Т.контр.

Манипулятор для лабораторных работ.

Н.контр.

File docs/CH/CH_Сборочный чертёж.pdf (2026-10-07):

14 | 5 | 7 | 13 | 12 6 | 9 18 | 3

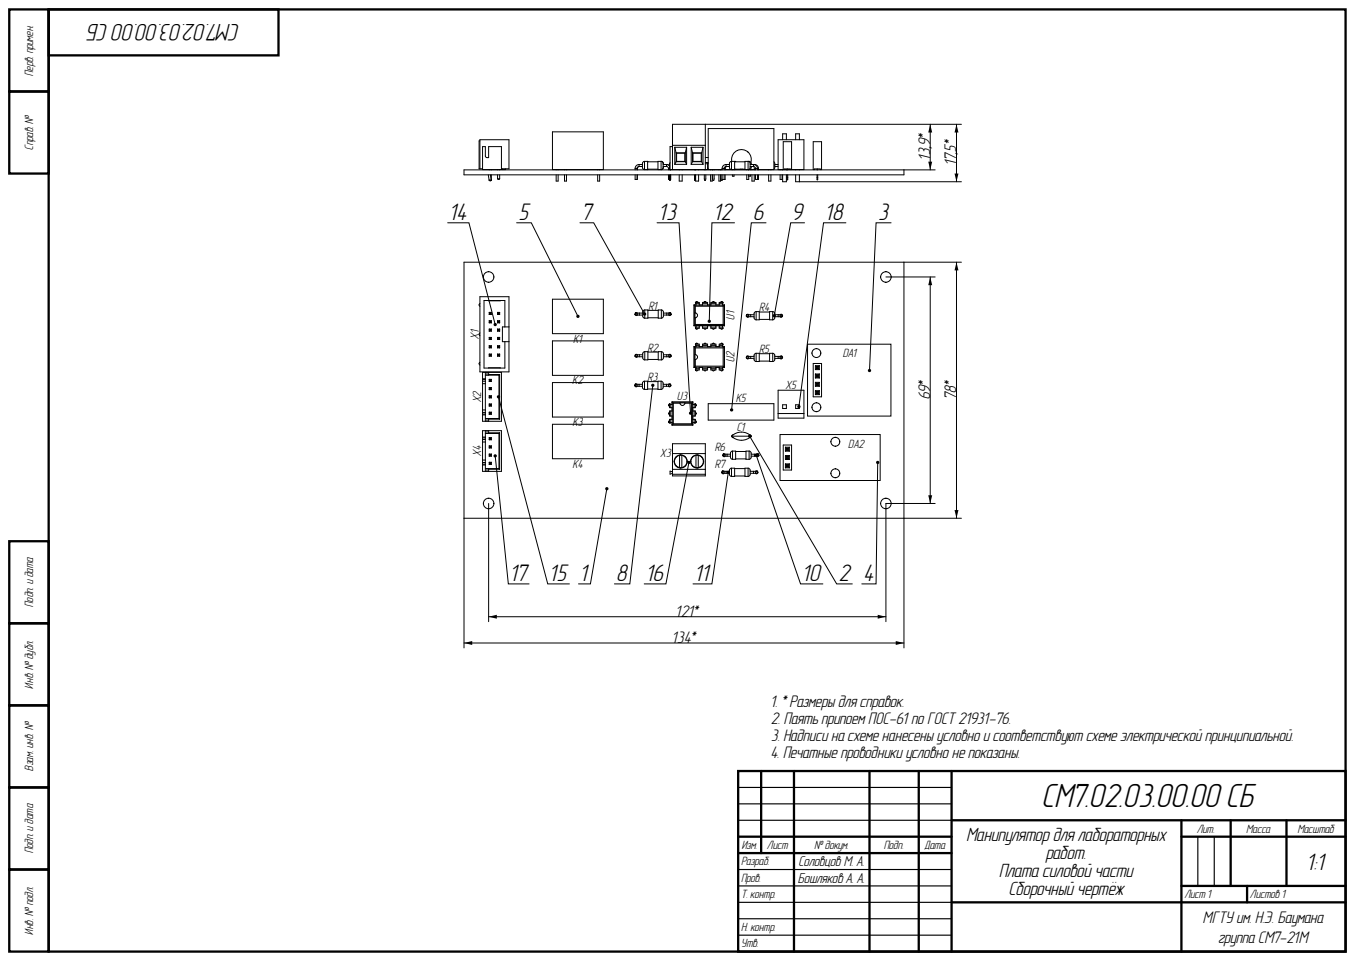
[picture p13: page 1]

Перв. примен. Справ. № Инв. № подл. Подп. и дата Взам. инв. № Инв. № дубл. Подп. и дата

1. * Размеры для справок.
2. Паять припоем ПОС-61 по ГОСТ 21931-76.
3. Надписи на схеме нанесены условно и соответствуют схеме электрической принципиальной.
4. Печатные проводники условно не показаны.

Манипулятор для лабораторных
работ. Плата силовой части

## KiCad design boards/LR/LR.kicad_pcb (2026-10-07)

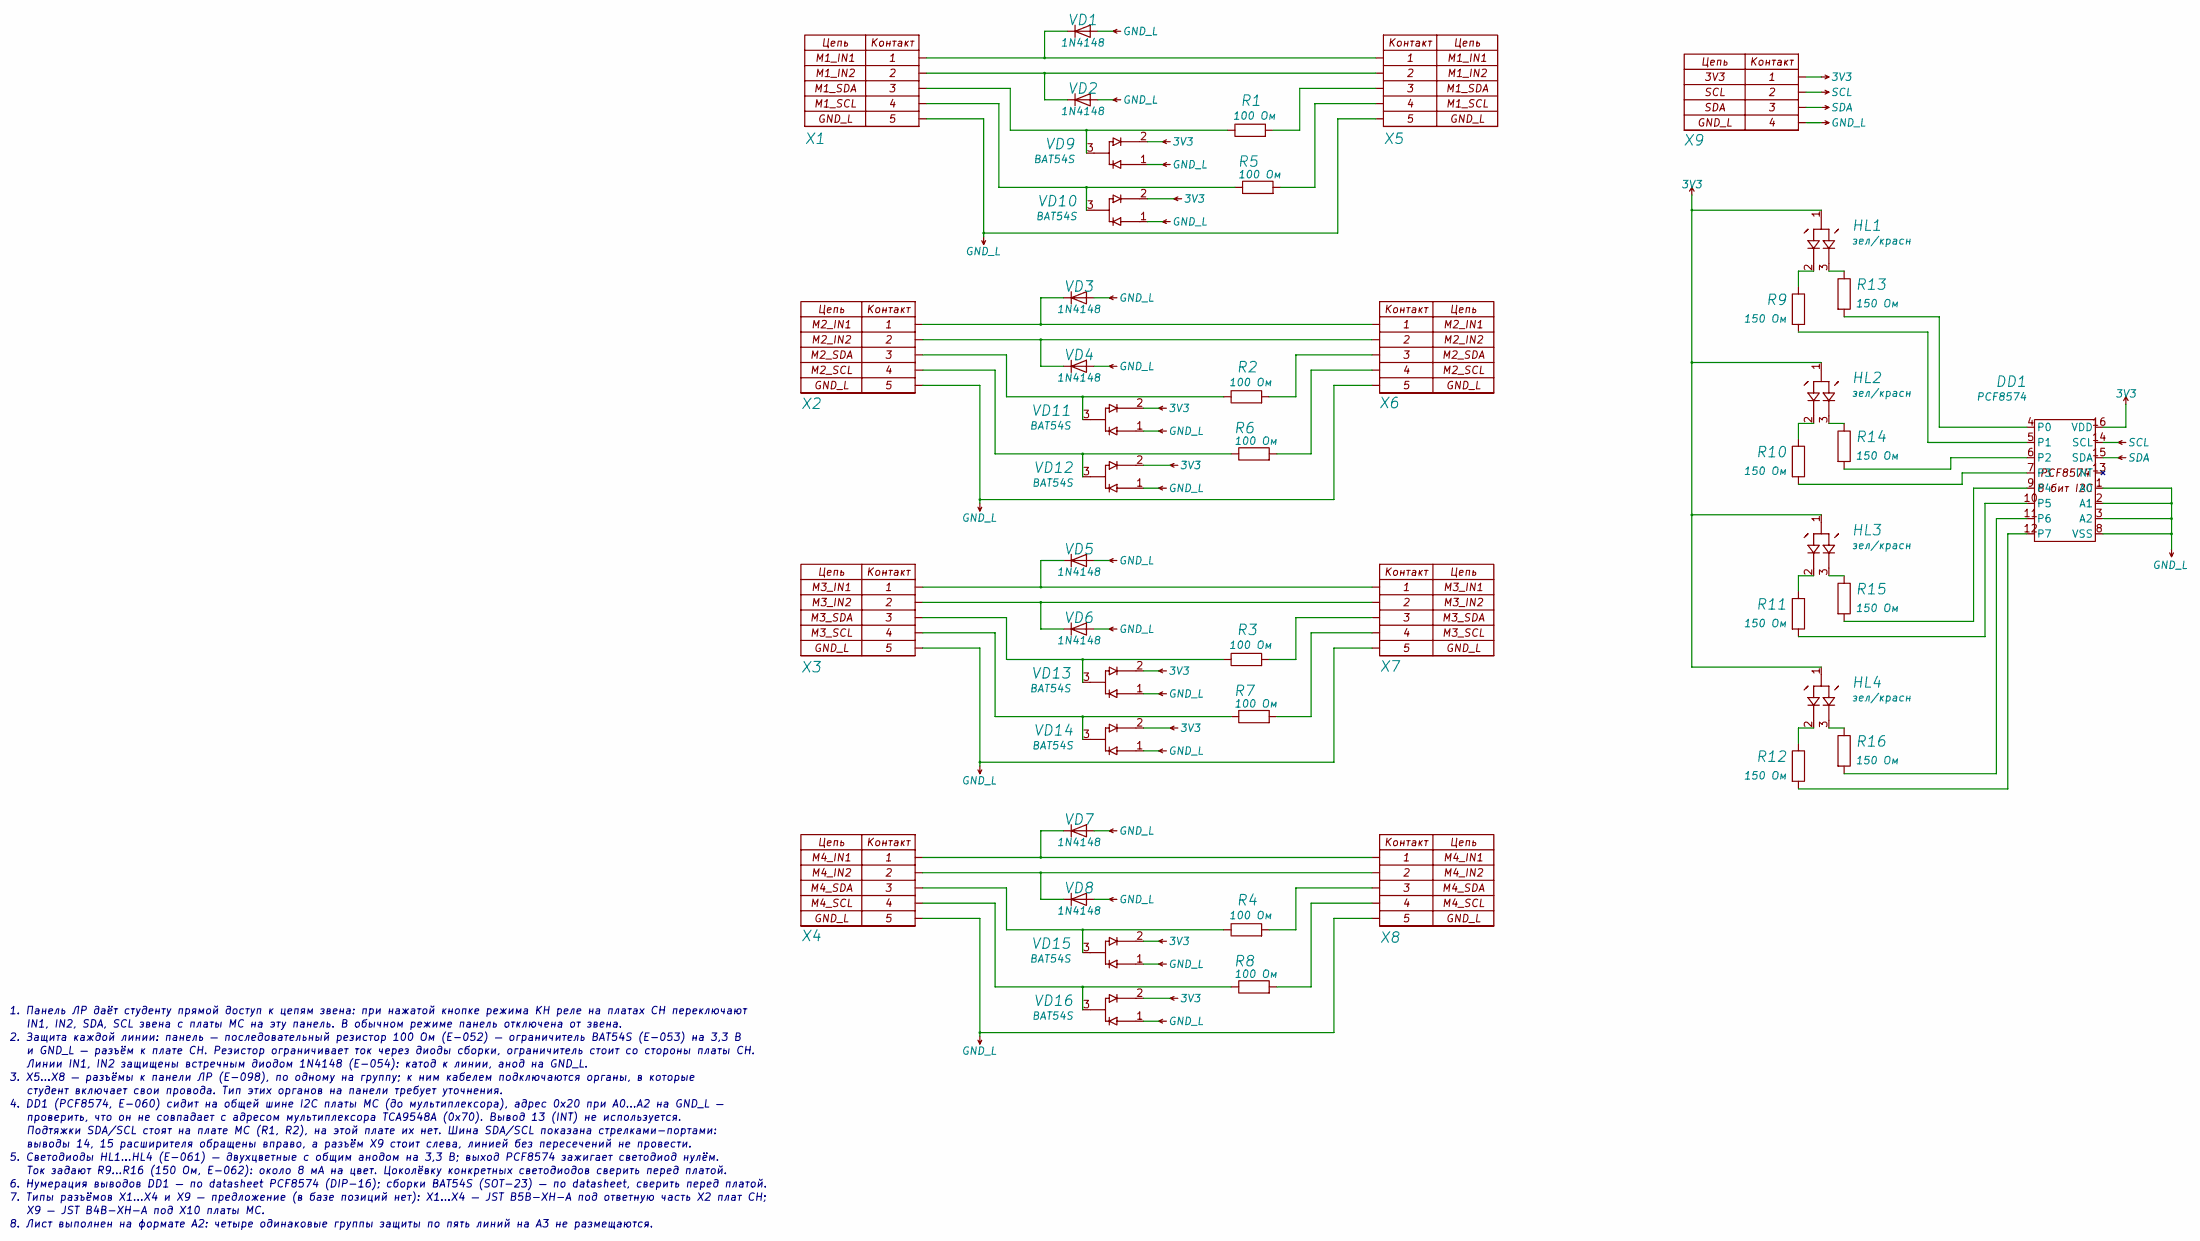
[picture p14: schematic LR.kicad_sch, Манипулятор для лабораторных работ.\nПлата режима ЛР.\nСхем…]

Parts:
DD1: PCF8574; DIP-16_W7.62mm
HL1, HL2, HL3, HL4: зел/красн; LED_Bicolor_5mm
R1, R2, R3, R4, R5, R6, R7, R8: 100 Ом; R_Axial_P10.16mm_V
R9, R10, R11, R12, R13, R14, R15, R16: 150 Ом; R_Axial_P10.16mm_V
VD1, VD2, VD3, VD4, VD5, VD6, VD7, VD8: 1N4148; D_DO-35_P7.62mm
VD9, VD10, VD11, VD12, VD13, VD14, VD15, VD16: BAT54S; SOT-23
X1, X2, X3, X4, X5, X6, X7, X8: B5B-XH-A; JST_XH_B5B-XH-A_L
X9: B4B-XH-A; JST_XH_B4B-XH-A_R

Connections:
3V3: DD1.16 (VDD), HL1.1 (A), HL2.1 (A), HL3.1 (A), HL4.1 (A), VD9.2 (K), VD10.2 (K), VD11.2 (K), VD12.2 (K), VD13.2 (K), VD14.2 (K), VD15.2 (K), VD16.2 (K), X9.1 (3V3)
GND_L: DD1.1 (A0), DD1.2 (A1), DD1.3 (A2), DD1.8 (VSS), VD1.2 (A), VD2.2 (A), VD3.2 (A), VD4.2 (A), VD5.2 (A), VD6.2 (A), VD7.2 (A), VD8.2 (A), VD9.1 (A), VD10.1 (A), VD11.1 (A), VD12.1 (A), VD13.1 (A), VD14.1 (A), VD15.1 (A), VD16.1 (A), X1.5 (GND_L), X2.5 (GND_L), X3.5 (GND_L), X4.5 (GND_L), X5.5 (GND_L), X6.5 (GND_L), X7.5 (GND_L), X8.5 (GND_L), X9.4 (GND_L)
unnamed: DD1.4 (P0), R13.2
unnamed: DD1.5 (P1), R9.2
unnamed: DD1.6 (P2), R14.2
unnamed: DD1.7 (P3), R10.2
unnamed: DD1.9 (P4), R15.2
unnamed: DD1.10 (P5), R11.2
unnamed: DD1.11 (P6), R16.2
unnamed: DD1.12 (P7), R12.2
unnamed: HL1.2 (K1), R9.1
unnamed: HL1.3 (K2), R13.1
unnamed: HL2.2 (K1), R10.1
unnamed: HL2.3 (K2), R14.1
unnamed: HL3.2 (K1), R11.1
unnamed: HL3.3 (K2), R15.1
unnamed: HL4.2 (K1), R12.1
unnamed: HL4.3 (K2), R16.1
unnamed: VD1.1 (K), X1.1 (M1_IN1), X5.1 (M1_IN1)
unnamed: VD2.1 (K), X1.2 (M1_IN2), X5.2 (M1_IN2)
unnamed: VD3.1 (K), X2.1 (M2_IN1), X6.1 (M2_IN1)
unnamed: VD4.1 (K), X2.2 (M2_IN2), X6.2 (M2_IN2)
unnamed: VD5.1 (K), X3.1 (M3_IN1), X7.1 (M3_IN1)
unnamed: VD6.1 (K), X3.2 (M3_IN2), X7.2 (M3_IN2)
unnamed: VD7.1 (K), X4.1 (M4_IN1), X8.1 (M4_IN1)
unnamed: VD8.1 (K), X4.2 (M4_IN2), X8.2 (M4_IN2)
unnamed: R1.1, VD9.3 (IN), X1.3 (M1_SDA)
unnamed: R5.1, VD10.3 (IN), X1.4 (M1_SCL)
unnamed: R2.1, VD11.3 (IN), X2.3 (M2_SDA)
unnamed: R6.1, VD12.3 (IN), X2.4 (M2_SCL)
unnamed: R3.1, VD13.3 (IN), X3.3 (M3_SDA)
unnamed: R7.1, VD14.3 (IN), X3.4 (M3_SCL)
unnamed: R4.1, VD15.3 (IN), X4.3 (M4_SDA)
unnamed: R8.1, VD16.3 (IN), X4.4 (M4_SCL)
unnamed: R5.2, X5.4 (M1_SCL)
unnamed: R1.2, X5.3 (M1_SDA)
unnamed: R6.2, X6.4 (M2_SCL)
unnamed: R2.2, X6.3 (M2_SDA)
unnamed: R7.2, X7.4 (M3_SCL)
unnamed: R3.2, X7.3 (M3_SDA)
unnamed: R8.2, X8.4 (M4_SCL)
unnamed: R4.2, X8.3 (M4_SDA)
SCL: DD1.14 (SCL), X9.2 (SCL)
SDA: DD1.15 (SDA), X9.3 (SDA)

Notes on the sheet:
Линии IN1, IN2 защищены встречным диодом 1N4148 (E-054): катод к линии, анод на GND_L.
2. Защита каждой линии: панель — последовательный резистор 100 Ом (E-052) — ограничитель BAT54S (E-053) на 3,3 В
IN1, IN2, SDA, SCL звена с платы MC на эту панель. В обычном режиме панель отключена от звена.
3. X5…X8 — разъёмы к панели ЛР (E-098), по одному на группу; к ним кабелем подключаются органы, в которые
Ток задают R9…R16 (150 Ом, E-062): около 8 мА на цвет. Цоколёвку конкретных светодиодов сверить перед платой.
X9 — JST B4B-XH-A под X10 платы MC.
проверить, что он не совпадает с адресом мультиплексора TCA9548A (0x70). Вывод 13 (INT) не используется.
7. Типы разъёмов X1…X4 и X9 — предложение (в базе позиций нет): X1…X4 — JST B5B-XH-A под ответную часть X2 плат CH;
5. Светодиоды HL1…HL4 (E-061) — двухцветные с общим анодом на 3,3 В; выход PCF8574 зажигает светодиод нулём.
1. Панель ЛР даёт студенту прямой доступ к цепям звена: при нажатой кнопке режима KH реле на платах CH переключают
выводы 14, 15 расширителя обращены вправо, а разъём X9 стоит слева, линией без пересечений не провести.
8. Лист выполнен на формате A2: четыре одинаковые группы защиты по пять линий на A3 не размещаются.
студент включает свои провода. Тип этих органов на панели требует уточнения.
Подтяжки SDA/SCL стоят на плате MC (R1, R2), на этой плате их нет. Шина SDA/SCL показана стрелками-портами:
и GND_L — разъём к плате CH. Резистор ограничивает ток через диоды сборки, ограничитель стоит со стороны платы CH.
6. Нумерация выводов DD1 — по datasheet PCF8574 (DIP-16); сборки BAT54S (SOT-23) — по datasheet, сверить перед платой.
4. DD1 (PCF8574, E-060) сидит на общей шине I2C платы MC (до мультиплексора), адрес 0x20 при A0…A2 на GND_L —

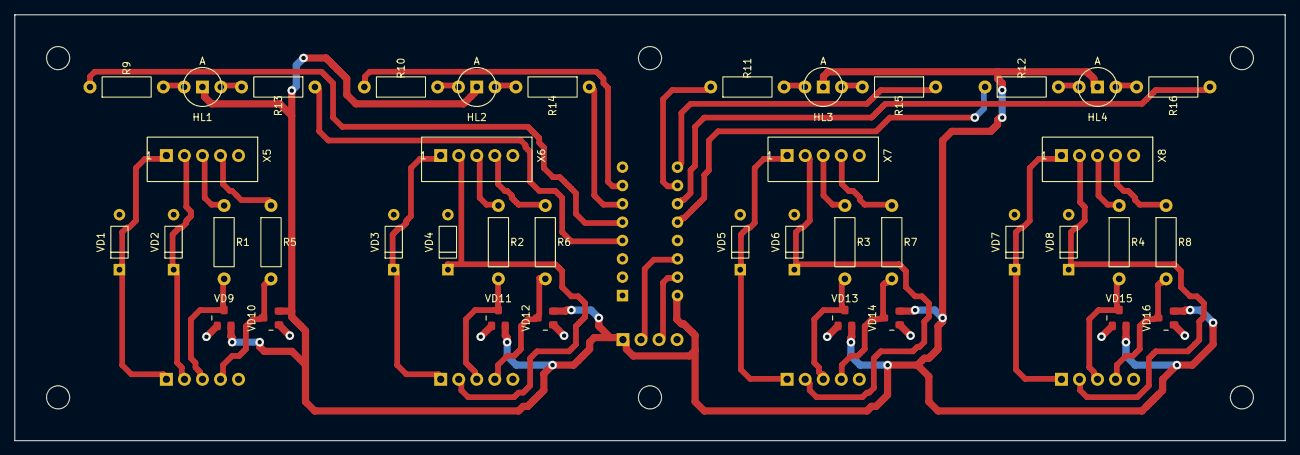
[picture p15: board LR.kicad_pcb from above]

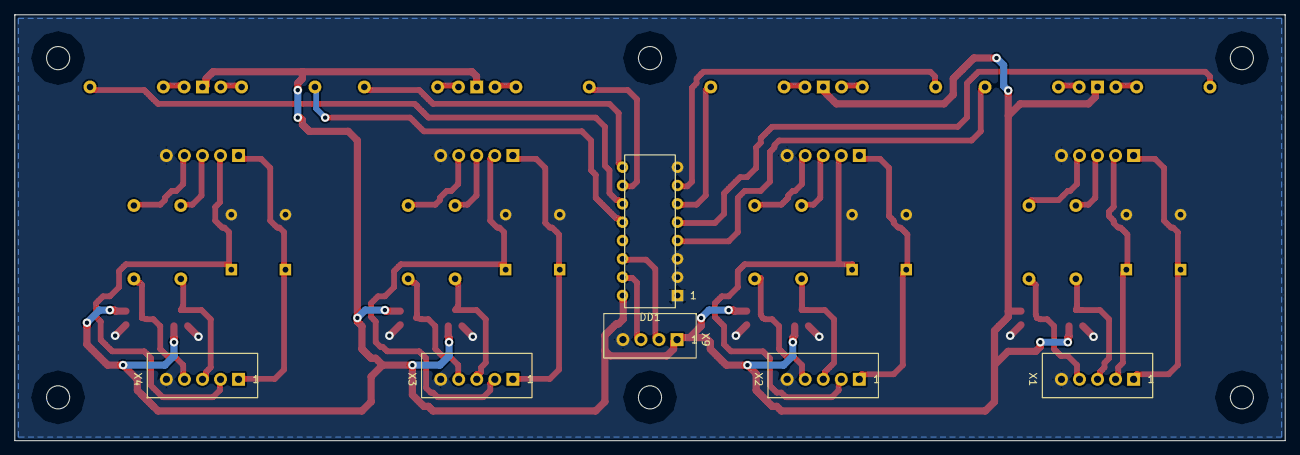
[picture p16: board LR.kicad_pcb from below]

Board: 2 copper layers, 176.0 x 59.0 mm, 52 parts (6 on the bottom side), 44 nets.

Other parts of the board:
H1, H2, H3, H4, H5, H6: M3; MountingHole_3.2mm_M3

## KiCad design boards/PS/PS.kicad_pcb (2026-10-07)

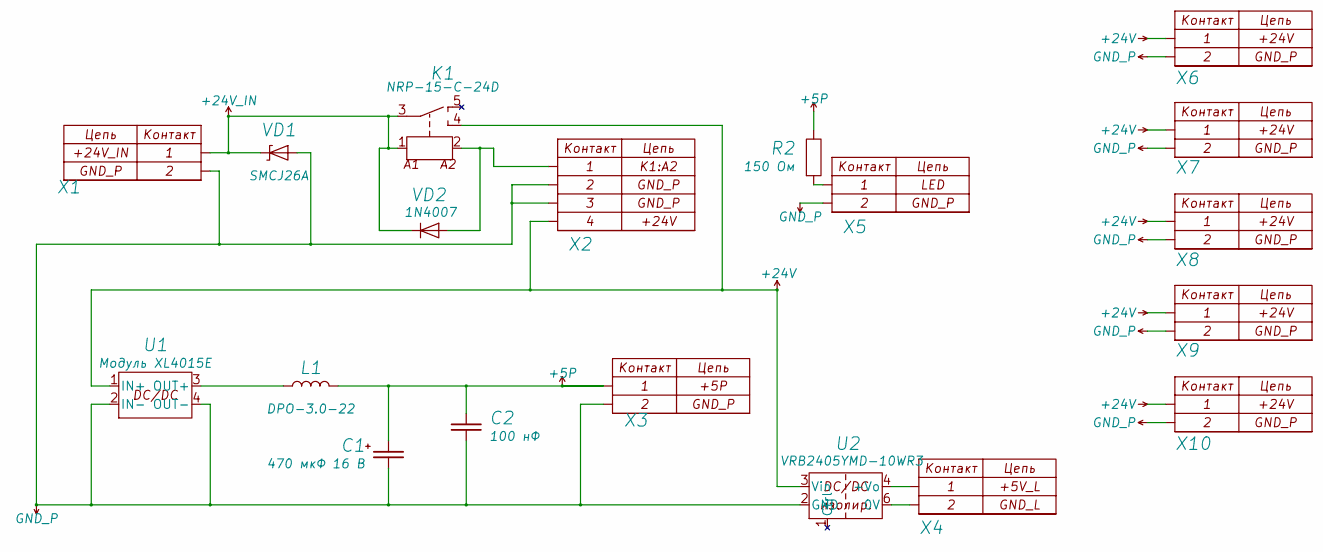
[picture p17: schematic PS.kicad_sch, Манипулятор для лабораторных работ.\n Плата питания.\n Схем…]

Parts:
C1: 470 мкФ 16 В; CP_Radial_D8.0mm_P3.50mm
C2: 100 нФ; C_Disc_P5.00mm
K1: NRP-15-C-24D; Relay_NRP-15_1C
L1: DPO-3.0-22; L_Toroid_D20_P10.16mm
R2: 150 Ом; R_Axial_P10.16mm_V
U1: Модуль XL4015E; Module_XL4015E_zone
U2: VRB2405YMD-10WR3; DCDC_Mornsun_YMD_25.4x25.4
VD1: SMCJ26A; D_SMC
VD2: 1N4007; D_DO-41_P10.16mm
X1: DG301-5.0-02P-12; TB_DG301-5.0_2P
X2: B4B-XH-A; JST_XH_B4B-XH-A
X3, X4: B2P-VH; JST_VH_B2P-VH_V
X5: B2B-XH-A; JST_XH_B2B-XH-A
X6, X7, X8, X9, X10: DG301-5.0-02P-12; TB_DG301-5.0_2P_V

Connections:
+5P: C1.1, C2.1, L1.2, R2.1, X3.1 (+5P)
+24V: K1.4 (NO), U1.1 (IN+), U2.3 (Vin), X2.4 (+24V), X6.1 (+24V), X7.1 (+24V), X8.1 (+24V), X9.1 (+24V), X10.1 (+24V)
+24V_IN: K1.1 (A1), K1.3 (COM), VD1.1 (K), VD2.1 (K), X1.1 (+24V_IN)
GND_P: C1.2, C2.2, U1.2 (IN-), U1.4 (OUT-), U2.2 (GND), VD1.2 (A), X1.2 (GND_P), X2.2 (GND_P), X2.3 (GND_P), X3.2 (GND_P), X5.2 (GND_P), X6.2 (GND_P), X7.2 (GND_P), X8.2 (GND_P), X9.2 (GND_P), X10.2 (GND_P)
unnamed: K1.2 (A2), VD2.2 (A), X2.1 (K1:A2)
unnamed: L1.1, U1.3 (OUT+)
unnamed: U2.6 (0V), X4.2 (GND_L)
unnamed: U2.4 (+Vo), X4.1 (+5V_L)
unnamed: R2.2, X5.1 (LED)

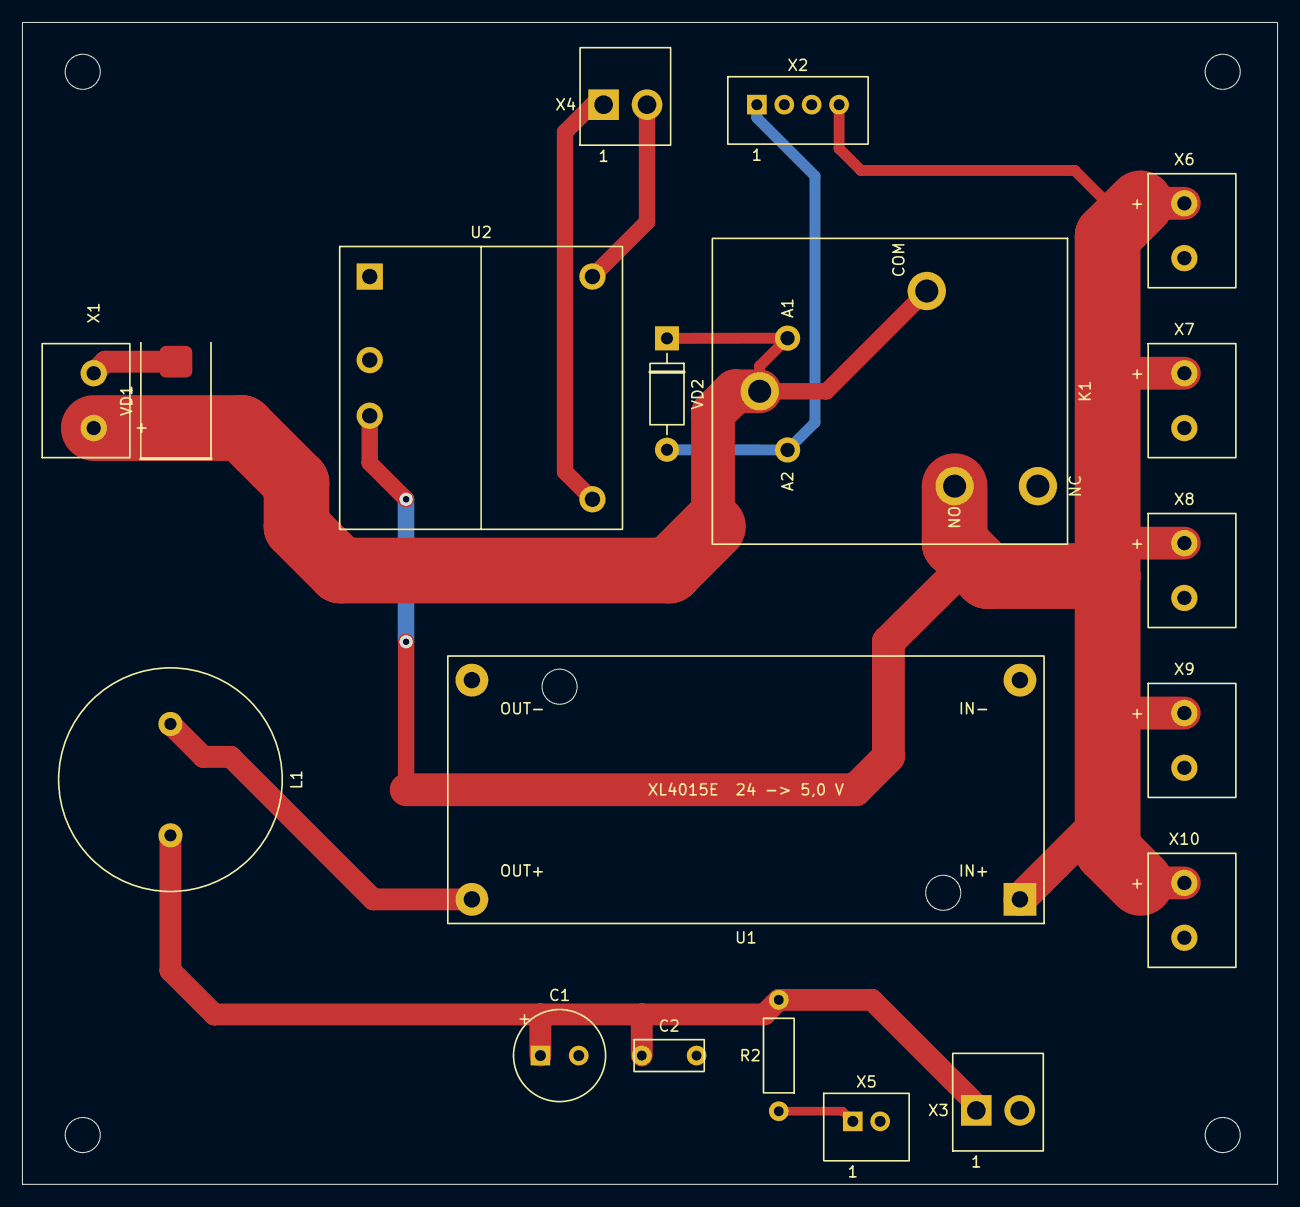
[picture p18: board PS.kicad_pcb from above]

Board: 2 copper layers, 114.5 x 106.0 mm, 23 parts (0 on the bottom side), 9 nets.

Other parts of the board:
H1, H2, H3, H4: M3; MountingHole_3.2mm_M3

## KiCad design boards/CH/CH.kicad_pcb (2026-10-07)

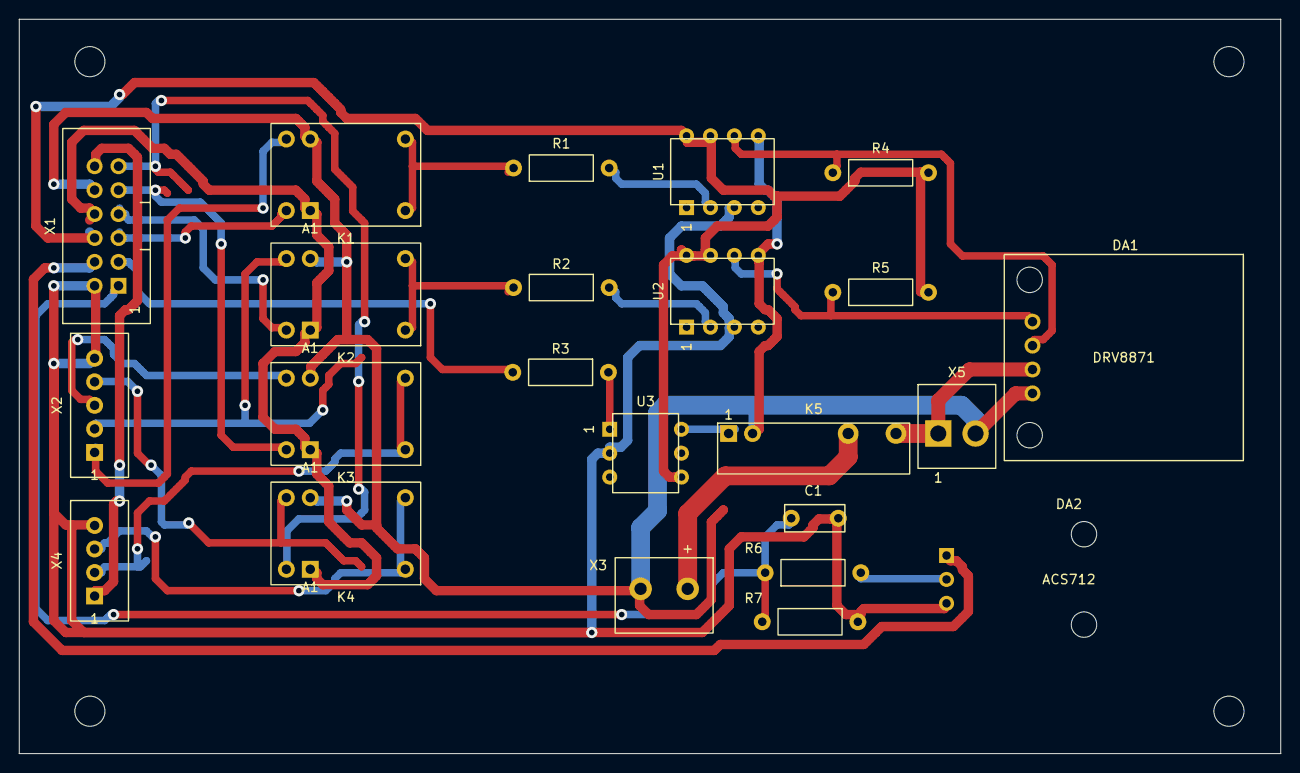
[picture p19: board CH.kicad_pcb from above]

Board: 2 copper layers, 134.0 x 78.0 mm, 27 parts (0 on the bottom side), 29 nets.

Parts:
C1: 100 нФ; C_Disc_P5.00mm
DA1: DRV8871; Module_DRV8871
DA2: ACS712-20A; Module_ACS712
H1, H2, H3, H4: M3; MountingHole_3.2mm_M3
K1, K2, K3, K4: NRP-02-C-05DH; Relay_NRP-02_1C
K5: HF49FD/005-1H11; Relay_HF49FD_1A
R1, R2: 220 Ом; R_Axial_P10.16mm_V
R3: 150 Ом; R_Axial_P10.16mm_V
R4, R5: 4,7 кОм; R_Axial_P10.16mm_V
R6: 10 кОм; R_Axial_P10.16mm_V
R7: 20 кОм; R_Axial_P10.16mm_V
U1, U2: 6N137; DIP-8_W7.62mm
U3: КР293КП2Б; DIP-6_W7.62mm
X1: BH-12 (2×6); IDC-Header_2x06_P2.54mm_Vertical_D
X2: B5B-XH-A; JST_XH_B5B-XH-A_L
X3: DG301-5.0-02P; TB_DG301-5.0_2P_V
X4: B4B-XH-A; JST_XH_B4B-XH-A_L
X5: B2P-VH; JST_VH_B2P-VH

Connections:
3V3: X1.12 (3V3), X4.1 (3V3)
+5P: R4.1, R5.1, U1.7 (VE), U1.8 (VCC), U2.7 (VE), U2.8 (VCC), U3.4 (OUT), X1.6 (+5P)
+5V_L: DA2.1, X1.4 (+5V_L)
+24V: K5.3, X3.1 (+24V)
+24V_M: DA1.1, K5.4, X5.1
CURR: C1.1, R6.2, R7.1, X1.1 (CURR)
GND_L: C1.2, DA2.3, R7.2, U1.3 (K), U2.3 (K), U3.2 (K), X1.2 (GND_L), X2.5 (GND_L), X4.4 (GND_L)
GND_P: DA1.2, K1.2, K2.2, K3.2, K4.2, K5.2, U1.5 (GND), U2.5 (GND), X1.10 (GND_P), X3.2 (GND_P), X5.2
IN1_LR: K1.4, X2.1 (IN1_LR)
IN2_LR: K2.4, X2.2 (IN2_LR)
KH: K1.1, K2.1, K3.1, K4.1, X1.8 (KH)
unnamed: DA1.3, R4.2, U1.6 (VO)
unnamed: DA1.4, R5.2, U2.6 (VO)
unnamed: DA2.2, R6.1
unnamed: K1.3, R1.2
unnamed: K1.5, X1.5 (IN1)
unnamed: K2.3, R2.1
unnamed: K2.5, X1.7 (IN2)
unnamed: K3.3, X4.2 (SDA)
unnamed: K3.5, X1.9 (SDA)
unnamed: K4.3, X4.3 (SCL)
unnamed: K4.5, X1.11 (SCL)
unnamed: K5.1, U3.6 (OUT)
unnamed: R1.1, U1.2 (A)
unnamed: R2.2, U2.2 (A)
unnamed: R3.2, U3.1 (A)
RELE: R3.1, X1.3 (RELE)
SCL_LR: K4.4, X2.4 (SCL_LR)
SDA_LR: K3.4, X2.3 (SDA_LR)

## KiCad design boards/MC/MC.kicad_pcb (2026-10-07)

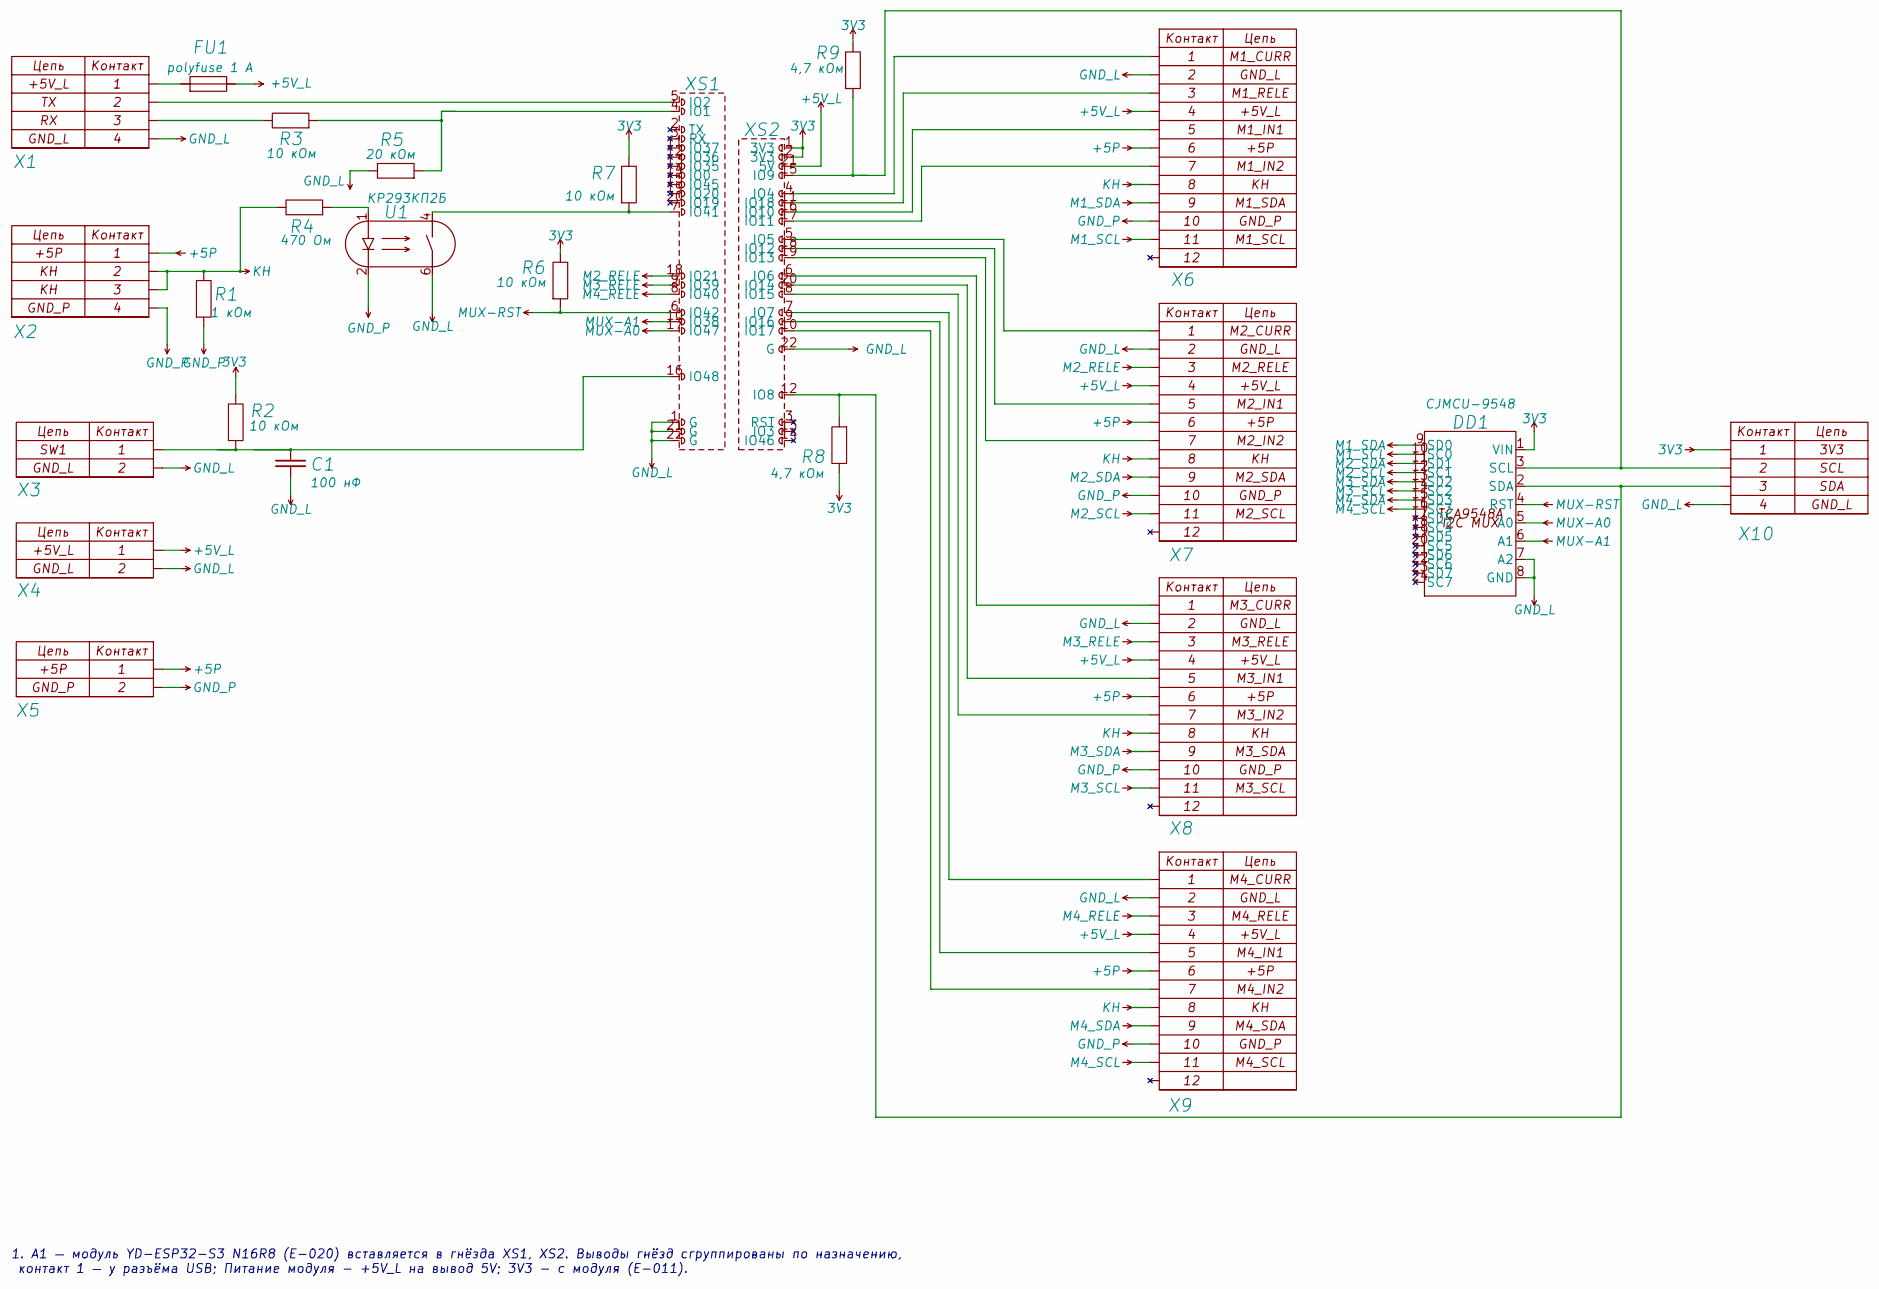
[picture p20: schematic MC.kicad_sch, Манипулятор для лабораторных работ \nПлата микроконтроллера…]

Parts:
C1: 100 нФ; C_Disc_P5.00mm
DD1: CJMCU-9548; Module_CJMCU-9548
FU1: polyfuse 1 А; Fuse_PTC_Radial_P5.08mm
R1: 1 кОм; R_Axial_P10.16mm_V
R2, R3, R7: 10 кОм; R_Axial_P10.16mm_V
R4: 470 Ом; R_Axial_P10.16mm_V
R5: 20 кОм; R_Axial_P10.16mm_V
R6: 10 кОм; R_Axial_P10.16mm
R8, R9: 4,7 кОм; R_Axial_P10.16mm
U1: КР293КП2Б; DIP-6_W7.62mm_H
X1, X2: B4B-XH-A; JST_XH_B4B-XH-A_L
X3: B2B-XH-A; JST_XH_B2B-XH-A_L
X4, X5: DG301-5.0-02P; TB_DG301-5.0_2P_R
X6, X7, X8, X9: BH-12 (2×6); IDC-Header_2x06_P2.54mm_Vertical
X10: B4B-XH-A; JST_XH_B4B-XH-A_R
XS1, XS2: PBS-22; PinSocket_1x22_P2.54mm_Vertical

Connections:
3V3: DD1.1 (VIN), R2.1, R6.1, R7.1, R8.1, R9.1, X10.1 (3V3), XS2.1 (3V3), XS2.2 (3V3)
+5P: X2.1 (+5P), X5.1 (+5P), X6.6 (+5P), X7.6 (+5P), X8.6 (+5P), X9.6 (+5P)
+5V_L: FU1.2, X4.1 (+5V_L), X6.4 (+5V_L), X7.4 (+5V_L), X8.4 (+5V_L), X9.4 (+5V_L), XS2.21 (5V)
GND_L: C1.2, DD1.7 (A2), DD1.8 (GND), R5.1, U1.6 (OUT), X1.4 (GND_L), X3.2 (GND_L), X4.2 (GND_L), X6.2 (GND_L), X7.2 (GND_L), X8.2 (GND_L), X9.2 (GND_L), X10.4 (GND_L), XS1.1 (G), XS1.21 (G), XS1.22 (G), XS2.22 (G)
GND_P: R1.2, U1.2 (K), X2.4 (GND_P), X5.2 (GND_P), X6.10 (GND_P), X7.10 (GND_P), X8.10 (GND_P), X9.10 (GND_P)
KH: R1.1, R4.1, X2.2 (KH), X2.3 (KH), X6.8 (KH), X7.8 (KH), X8.8 (KH), X9.8 (KH)
M1_SCL: DD1.10 (SC0), X6.11 (M1_SCL)
M1_SDA: DD1.9 (SD0), X6.9 (M1_SDA)
M2_RELE: X7.3 (M2_RELE), XS1.18 (IO21)
M2_SCL: DD1.12 (SC1), X7.11 (M2_SCL)
M2_SDA: DD1.11 (SD1), X7.9 (M2_SDA)
M3_RELE: X8.3 (M3_RELE), XS1.9 (IO39)
M3_SCL: DD1.14 (SC2), X8.11 (M3_SCL)
M3_SDA: DD1.13 (SD2), X8.9 (M3_SDA)
M4_RELE: X9.3 (M4_RELE), XS1.8 (IO40)
M4_SCL: DD1.16 (SC3), X9.11 (M4_SCL)
M4_SDA: DD1.15 (SD3), X9.9 (M4_SDA)
MUX-A0: DD1.5 (A0), XS1.17 (IO47)
MUX-A1: DD1.6 (A1), XS1.10 (IO38)
MUX-RST: DD1.4 (RST), R6.2, XS1.6 (IO42)
unnamed: DD1.3 (SCL), R9.2, X10.2 (SCL), XS2.15 (IO9)
unnamed: DD1.2 (SDA), R8.2, X10.3 (SDA), XS2.12 (IO8)
unnamed: R4.2, U1.1 (A)
unnamed: FU1.1, X1.1 (+5V_L)
unnamed: R3.1, X1.3 (RX)
unnamed: X1.2 (TX), XS1.5 (IO2)
unnamed: C1.1, R2.2, X3.1 (SW1), XS1.16 (IO48)
unnamed: X6.1 (M1_CURR), XS2.4 (IO4)
unnamed: X6.5 (M1_IN1), XS2.16 (IO10)
unnamed: X6.7 (M1_IN2), XS2.17 (IO11)
unnamed: X6.3 (M1_RELE), XS2.11 (IO18)
unnamed: X7.1 (M2_CURR), XS2.5 (IO5)
unnamed: X7.5 (M2_IN1), XS2.18 (IO12)
unnamed: X7.7 (M2_IN2), XS2.19 (IO13)
unnamed: X8.1 (M3_CURR), XS2.6 (IO6)
unnamed: X8.5 (M3_IN1), XS2.20 (IO14)
unnamed: X8.7 (M3_IN2), XS2.8 (IO15)
unnamed: X9.1 (M4_CURR), XS2.7 (IO7)
unnamed: X9.5 (M4_IN1), XS2.9 (IO16)
unnamed: X9.7 (M4_IN2), XS2.10 (IO17)
unnamed: R3.2, R5.2, XS1.4 (IO1)
unnamed: R7.2, U1.4 (OUT), XS1.7 (IO41)

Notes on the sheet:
1. A1 — модуль YD-ESP32-S3 N16R8 (E-020) вставляется в гнёзда XS1, XS2. Выводы гнёзд сгруппированы по назначению,
контакт 1 — у разъёма USB; Питание модуля - +5V_L на вывод 5V; 3V3 - с модуля (E-011).

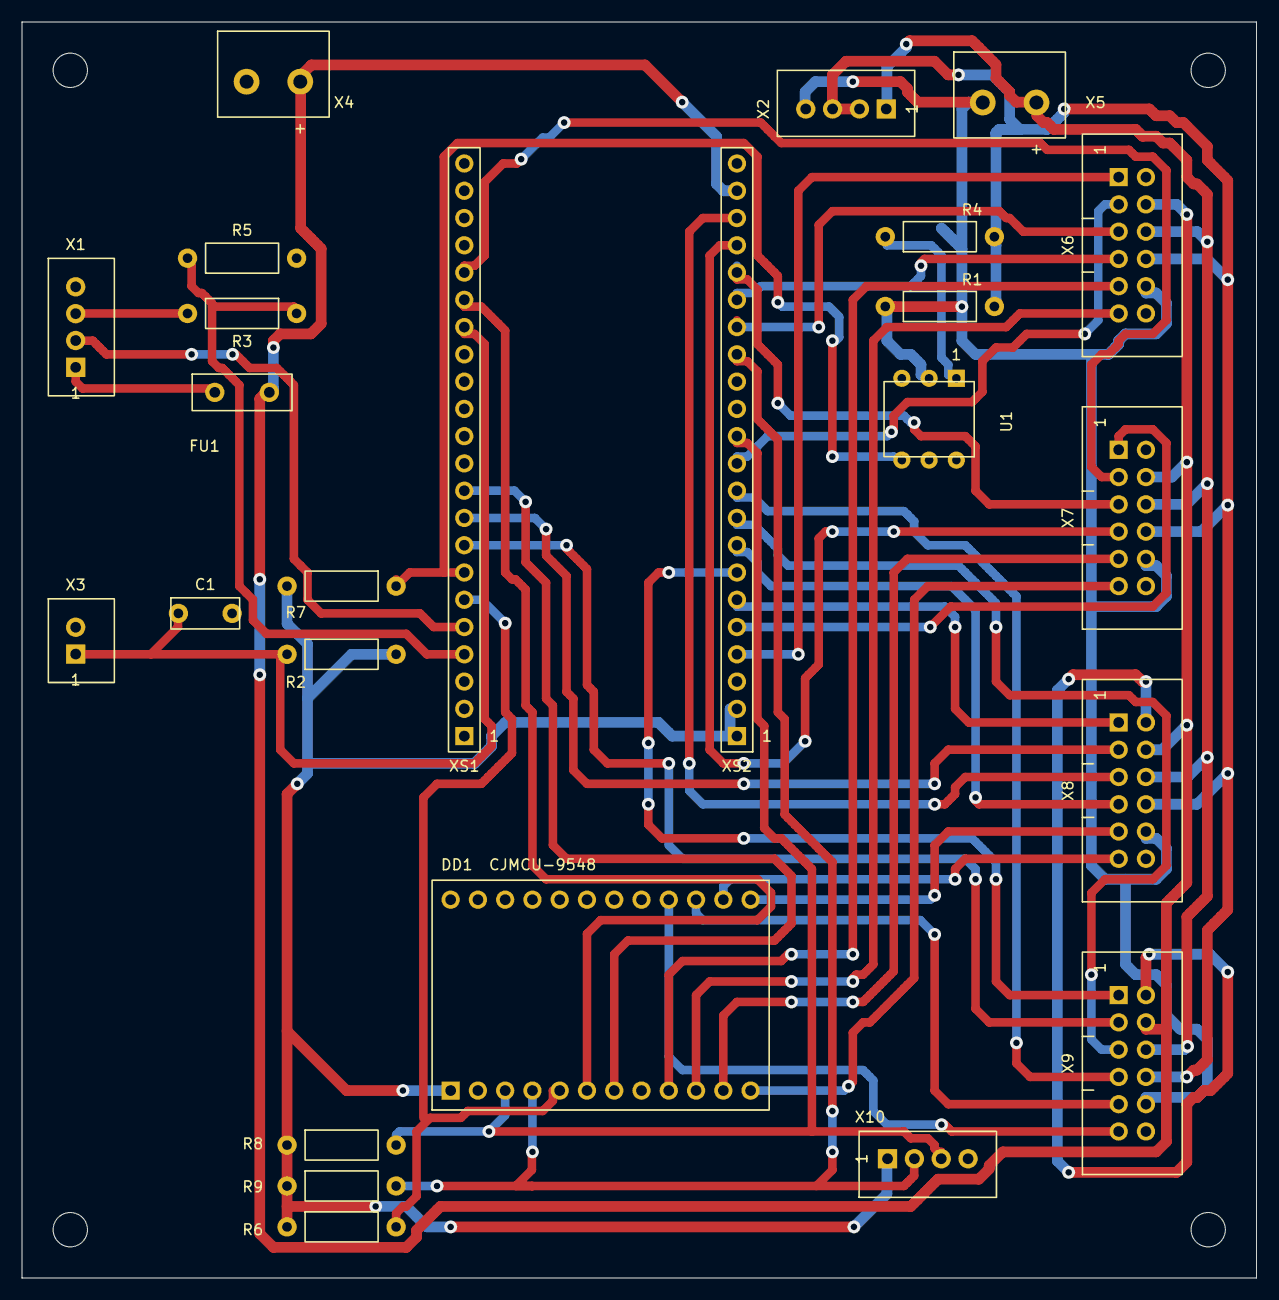
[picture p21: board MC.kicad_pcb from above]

Board: 2 copper layers, 115.0 x 117.0 mm, 29 parts (0 on the bottom side), 42 nets.

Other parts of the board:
H1, H2, H3, H4: M3; MountingHole_3.2mm_M3

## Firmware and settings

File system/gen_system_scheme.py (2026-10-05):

#!/usr/bin/env python3
"""Функциональная схема стенда, лист Э2 (A2, ГОСТ, шрифт GOST 2.304).

Геометрия и подписи хранятся рядом в functional_scheme.json (дамп листа),
правки задаются списками EDIT_TEXT / ADD_TEXT ниже. PDF руками не править —
менять этот файл и перегенерировать из корня репозитория:

    python3 system/gen_system_scheme.py

Полные правила оформления листа — в скилле create-func-scheme.
Шрифт: положить TTF из lib/fonts/ в ~/.fonts и выполнить fc-cache -f.

Цвет подписи: чёрный — решение утверждено, красный (0xC00000) — не утверждено
(см. легенду на листе). Статусы берутся из bom/Component_Base.xlsx.
"""
import json, math, re, sys
from pathlib import Path
import cairo

BLACK, RED = 0x000000, 0xC00000

# ── правки к дампу: индекс подписи -> что заменить ───────────────────────────
# cx — новый центр по X (если подпись центрируется в блоке)
EDIT_TEXT = {
    # двигатель утверждён 19.09.2026 (E-041), модель по каталогу nfpshop
    73: dict(t="Мотор-редуктор",  cx=1300.7),
    74: dict(t="5840-31ZY-DSH",   cx=1300.7),
    75: dict(t="24 В, i = 670",   cx=1300.7, color=BLACK),
    # механическая передача — без подробностей
    76: dict(t="Механическая передача", cx=1478.3, size=13.32, y=230.0),
    77: dict(t=""),
    # электроника схвата — коротко
    89: dict(t="Электроника схвата М5", cx=1491.0, y=684.5),
    90: dict(t=""),
    91: dict(t="контроллер --- (13)",   cx=1491.0, y=699.3),
    # силовая часть утверждена вместе с двигателем: метки (6), (7), (9) сняты
    66: dict(t=""),
    69: dict(t=""),
    72: dict(t=""),
    132: dict(t="Ток →ADC ESP32 (делитель 10 к + 20 к); ОС по току, «режим безопасности»",
              color=BLACK),
    # клеммы ЛР согласованы 19.09.2026 (E-051)
    85: dict(t=""),
    # токосъёмное кольцо: требование известно, изделие не выбрано
    53: dict(t="Токосъёмное кольцо не менее 5 А --- (16)"),
    57: dict(t="— питание ДПТ M2…M4 (3 двигателя × 1,2 А ном.; кольцо не менее 5 А);"),
    # подпись раздачи +5P — по центру своей стрелки (x = 942,4)
    119: dict(cx=879.0, y=720.0),
    120: dict(cx=879.0, y=731.0),
    121: dict(cx=879.0, y=742.0),
    # перекомпоновка узла +5P: XL4015E поднят над магистралью +24
    105: dict(cx=879.0, y=803.0),
    106: dict(cx=879.0, y=819.0),
    111: dict(t=""),                       # «+24 →остров» — магистраль теперь прямая
    # E-091 и E-073 утверждены 20.09.2026 — метки сняты
    50: dict(t="вход ESP32, GPIO48", color=BLACK),
    # редакция листа
    19: dict(t="Редакция 11; доска Miro + решения 13–19.09.2026"),
    152: dict(t="чёрным — утверждено Mikhail (13–19.09.2026)"),
}

# врезка в линию UART схвата и рамка вокруг подписи раздачи +5P:
# блоки рисуются поверх линий, белая заливка их перекрывает
BOX_X, BOX_W, BOX_CY, BOX_H = 1073.0, 107.7, 685.4, 56.7
P5_X, P5_W, P5_Y, P5_H = 825.1, 107.7, 706.0, 50.0        # подпись раздачи +5P
XL_X, XL_W, XL_Y, XL_H = 825.1, 107.8, 780.0, 57.1        # блок XL4015E над магистралью
AX = XL_X + XL_W / 2                                       # ось отводов (879,0)
BUS_Y = 875.6                                              # магистраль +24

# элементы исходного листа, которые эта компоновка заменяет:
# 100 — прежний блок XL4015E, 170/171 — стрелка реле → XL4015E,
# 113/114 — прежний отвод +5P, 105/106 — прежний обход +24 к изолятору
DEL_DRAW = {100, 105, 106, 113, 114, 170, 171}

def _arrow(x, y, d):
    """наконечник: вылет 7,6 pt, полураствор 4,8 pt; d = "up" или "right"."""
    if d == "up":
        return [["l", [x - 4.8, y + 7.6], [x, y]], ["l", [x, y], [x + 4.8, y + 7.6]]]
    return [["l", [x - 7.6, y - 4.8], [x, y]], ["l", [x, y], [x - 7.6, y + 4.8]]]

def _thin(items):
    return dict(items=items, color=[0.0, 0.0, 0.0], fill=None, width=1.01, dashes=None)
ADD_DRAW = [
    dict(items=[["re", [BOX_X, BOX_CY - BOX_H / 2, BOX_W, BOX_H]]],
         color=[0.0, 0.0, 0.0], fill=[1.0, 1.0, 1.0], width=1.97, dashes=None),
    dict(items=[["re", [P5_X, P5_Y, P5_W, P5_H]]],
         color=[0.0, 0.0, 0.0], fill=[1.0, 1.0, 1.0], width=1.97, dashes=None),
    dict(items=[["re", [XL_X, XL_Y, XL_W, XL_H]]],
         color=[0.0, 0.0, 0.0], fill=[1.0, 1.0, 1.0], width=1.97, dashes=None),
    # магистраль +24 идёт от реле напрямую к изолированному DC-DC
    _thin([["l", [799.7, BUS_Y], [951.9, BUS_Y]]]),
    _thin(_arrow(951.9, BUS_Y, "right")),
    # отвод магистрали вверх на XL4015E и далее раздача +5P
    _thin([["l", [AX, BUS_Y], [AX, XL_Y + XL_H]]]),
    _thin(_arrow(AX, XL_Y + XL_H, "up")),
    _thin([["l", [AX, XL_Y], [AX, P5_Y + P5_H]]]),
    _thin(_arrow(AX, P5_Y + P5_H, "up")),
]

ADD_TEXT = [
    dict(t="Защита ESP-RX",        cx=BOX_X + BOX_W / 2, y=675.2, size=10.78, color=BLACK),
    dict(t="от 5 В схвата",        cx=BOX_X + BOX_W / 2, y=689.2, size=10.78, color=BLACK),
    dict(t="делитель 10 к + 20 к",  cx=BOX_X + BOX_W / 2, y=703.2, size=10.78, color=BLACK),
]


# ── отрисовка ───────────────────────────────────────────────────────────────
def dash_of(s):
    if not s: return []
    n = [float(x) for x in re.findall(r"[\d.]+", str(s))]
    return n[:-1] if len(n) > 1 else []

def main(data_path, out_path):
    d = json.load(open(data_path, encoding="utf-8"))
    surf = cairo.PDFSurface(str(out_path), d["w"], d["h"])
    cr = cairo.Context(surf)
    cr.set_line_cap(cairo.LINE_CAP_BUTT); cr.set_line_join(cairo.LINE_JOIN_MITER)

    for n, dr in enumerate(list(d["draw"]) + ADD_DRAW):
        if n in DEL_DRAW:
            continue
        cur = None
        for it in dr["items"]:
            if it[0] == "l":
                (x1, y1), (x2, y2) = it[1], it[2]
                if cur != (x1, y1): cr.move_to(x1, y1)
                cr.line_to(x2, y2); cur = (x2, y2)
            elif it[0] == "re":
                x, y, w, h = it[1]; cr.rectangle(x, y, w, h); cur = None
            elif it[0] == "c":
                (x1, y1), (a, b), (c, e), (x2, y2) = it[1], it[2], it[3], it[4]
                if cur != (x1, y1): cr.move_to(x1, y1)
                cr.curve_to(a, b, c, e, x2, y2); cur = (x2, y2)
        if dr.get("closePath"): cr.close_path()
        if dr.get("fill"):
            cr.set_source_rgb(*dr["fill"])
            cr.fill_preserve() if dr.get("color") else cr.fill()
        if dr.get("color"):
            cr.set_source_rgb(*dr["color"])
            cr.set_line_width(dr["width"] or 0.3)
            ds = dash_of(dr.get("dashes")); cr.set_dash(ds if ds else [], 0)
            cr.stroke()
        cr.new_path()

    cr.select_font_face("GOST 2.304", cairo.FONT_SLANT_ITALIC, cairo.FONT_WEIGHT_NORMAL)

    def draw_text(t, x, y, size, color, dirv=(1.0, 0.0), cx=None):
        cr.set_font_size(size)
        cr.set_source_rgb(((color >> 16) & 255) / 255, ((color >> 8) & 255) / 255, (color & 255) / 255)
        if cx is not None:
            xb, yb, w, h, dx, dy = cr.text_extents(t)
            x = cx - w / 2 - xb
        cr.save(); cr.translate(x, y)
        if tuple(dirv) == (0.0, -1.0): cr.rotate(-math.pi / 2)
        cr.move_to(0, 0); cr.show_text(t); cr.restore()

    for i, s in enumerate(d["text"]):
        e = EDIT_TEXT.get(i, {})
        draw_text(e.get("t", s["t"]), s["x"], e.get("y", s["y"]),
                  e.get("size", s["size"]), e.get("color", s["color"]),
                  s.get("dir", (1.0, 0.0)), e.get("cx"))
    for a in ADD_TEXT:
        draw_text(a["t"], a.get("x", 0.0), a["y"], a["size"], a["color"],
                  a.get("dir", (1.0, 0.0)), a.get("cx"))

    surf.finish()
    print("записано:", out_path)

if __name__ == "__main__":
    here = Path(__file__).resolve().parent
    main(sys.argv[1] if len(sys.argv) > 1 else here / "functional_scheme.json",
         sys.argv[2] if len(sys.argv) > 2 else here / "functional_scheme_A2_v11.pdf")

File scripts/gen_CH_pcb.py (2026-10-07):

#!/usr/bin/env python3
"""Генератор печатной платы CH (силовая часть, 4 + 1 экземпляр) манипулятора для лабораторных работ.

Создаёт boards/CH/CH.kicad_pcb (формат KiCad 9, читается KiCad 10) и footprint'ы в lib/footprints/manipulator.pretty.
Общая часть (класс FP, библиотека посадочных мест, трассировщик, зоны, сборка) — scripts/pcb_common.py.
Схема — boards/CH/CH.kicad_sch (scripts/gen_CH_sch.py).

Исходные данные посадочных мест:
  K5 — HF49FD/005-1H11: по чертежу Hongfa (datasheet HF49FD, стр. 2): корпус 20 × 5 × 12,5, выводы 0 / 5,08 (контакты,
       ⌀1,2) и 15,24 / 17,78 (катушка, ⌀1); место повёрнуто: катушка слева (1, 2), контакт справа (3, 4) — 05.10.2026;
  DA2 — модуль ACS712-20A: плата 31 × 13 мм, гребёнка 2,54 (VCC, OUT, GND), клеммник 5,08 (IP+, IP-)
       (datasheethub.com, карточка модуля). Габарит и положение гребёнки СВЕРИТЬ по своему модулю;
  DA1 — модуль DRV8871 (клон Adafruit 3190): у оригинала два клеммника (VM/GND и OUT1/OUT2) и гребёнка IN1/IN2
       (learn.adafruit.com). У клонов состав выводов различается, поэтому место сделано РАЗЪЁМНЫМ (E-030,
       «посадочное место сделать разъёмным»): ряд из 6 отверстий 2,54 под гнездо или пайку проводами,
       контур модуля 25,4 × 20,3 нанесён на F.Fab справочно — СВЕРИТЬ по своему модулю;
  K1…K4 — NRP-02-C-05DH: по чертежу NCR (datasheet NRP-02, стр. 2): корпус 15,5 × 10,5 × 11,5, 6 выводов ⌀1,
       ряды 7,6, колонки 0 / 2,54 / 12,64 (вид снизу); место уточнено 05.10.2026, на плате реле повёрнуты на 180°
       (COM к R1…R3 и X4, контакты NC/NO — к X1, X2);
  U1, U2 — 6N137 в DIP-8 (ряды 7,62, шаг 2,54) — стандартный корпус;
  U3 — КР293КП2Б в DIP-6, X1 — IDC BH-12, X2/X3 — JST XH, X4/X5 — клеммники DG301-5.0 — места уже
       в библиотеке (см. docs/PS-footprints.md).

Правила (Резонит, 2 слоя, FR-4 1,6, фольга 18 мкм): зазор 0,5, сигнальные 0,8, +5 — 1,0, силовые 2,0,
переходы 1,2/0,6. Гальваническая развязка: остров (логика MC и панели ЛР) — слева, силовая сторона — справа,
граница проходит внутри U1, U2, U3, DA2 и по контактам реле K1…K4; расстояние между медью сторон не менее 2 мм.

Компоновка (мм, от левого верхнего угла; плата 105 × 80), порядок установки узлов — по числу связей:
  1. X1 (к MC, 12 цепей обеих сторон) — левый верхний угол, повёрнут на 180° (место …_D, ключ к центру платы):
     нечётный ряд (слева направо CURR, RELE, NC1…NC4) смотрит вниз и уходит к реле напрямую, чётный (питание: GND_L,
     +5V_L, +5P, KH, GND_P, 3V3) — вверх и вдоль верхнего края к катушкам реле и оптронам. При ключе вверх четыре
     NC-цепи верхнего ряда выходили в две дорожки вдоль края, и Net-(K3-NC) не проходила. Делитель R6/R7/C1 —
     фильтр CURR у приёмника (на X1), а не у источника (DA2) — в левом нижнем углу острова, CURR идёт к X1.1 вдоль
     левого края;
  2. колонка реле режима K1…K4 на границе сторон (x = 39, шаг 14): катушки (KH, GND_P) к силовой стороне,
     контакты (NC от X1, NO от X2, COM) к острову; между X1 и колонкой — коридор 8 мм для NC и +5P;
  3. X2 (панель ЛР) и X3 (энкодер) — левый край напротив K1/K2 и K3/K4;
  4. правее границы — три строки «резистор → оптрон → подтяжка»: R1-U1-R4 (IN1), R2-U2-R5 (IN2), R3-U3 (RELE);
     все потребители +5P (U1, U2, U3, R4, R5) — в одном прямоугольнике 50…70 × 8…46;
  5. K5 (реле +24) под U3, катушкой к U3, контактами к X5/DA1; DA1 — правый верхний угол, гребёнкой вверх;
  6. DA2 (ACS712) — сразу под DA1, клеммами IP к X4: контур тока мотора OUT2 → IP+ → IP− → X4 короткий;
  7. X4 (мотор), X5 (+24) — колонка по правому краю.
  HPWL (check_pcb.py): 1677 мм (A1 — 1675; расстановка E до исправления footprint'ов — 1551). Разводка «plane»:
  45 переходов (A1 «hv» — 60; E — 26). 04.10.2026 исправлены зеркальные места: IDC (вывод 1 справа при ключе вверху)
  и JST _L (вывод 1 снизу) — из-за этого порядок цепей на X1 и X2 изменился, реле переставлены K4…K1 сверху вниз,
  строки оптронов и DA1/DA2/X4/X5 отражены по вертикали, делитель R6/R7/C1 ушёл в левый нижний угол. Компоновка
  после исправления ещё не оптимизирована: 24 дорожки с числом поворотов > 3, SCL_LR — 5 переходов. Чертежей корпуса, реле NRP-02
  и модулей нет — всё «сверить».

Запуск: python3 scripts/gen_CH_pcb.py; затем scripts/check_pcb.py CH и scripts/check_sch_pcb.py CH
"""
import sys
from pathlib import Path

sys.path.insert(0, str(Path(__file__).resolve().parent))
import doc_titles as dt                 # noqa: E402  наименования и обозначения
import pcb_common as pc                    # noqa: E402
from pcb_common import *                   # noqa: E402,F401,F403

pc.PROJECT = PROJECT = "CH"
pc.ROOT_UUID = ROOT_UUID = "5a1f7c42-9e38-4b61-8d07-3c52a9f1b6d4"
pc.BOARD_W, pc.BOARD_H = BOARD_W, BOARD_H = 100.0, 78.0
pc.TITLE, pc.REV = dt.item("CH"), "CH-A1"

# ---- цепи ------------------------------------------------------------------------------------------
UNNAMED = ["Net-(K1-COM)", "Net-(K2-COM)", "Net-(K3-COM)", "Net-(K4-COM)",
           "Net-(K1-NC)", "Net-(K2-NC)", "Net-(K3-NC)", "Net-(K4-NC)",
           "Net-(U1-A)", "Net-(U2-A)", "Net-(U3-A)", "Net-(K5-A1)",
           "Net-(U1-VO)", "Net-(U2-VO)", "Net-(DA2-OUT)", "Net-(DA1-OUT1)", "Net-(DA1-OUT2)", "Net-(DA2-IP-)"]
NC = [f"unconnected-(U1-Pad{p})" for p in (1, 4)] + [f"unconnected-(U2-Pad{p})" for p in (1, 4)] + \
     ["unconnected-(U3-Pad3)", "unconnected-(U3-Pad5)"]
set_nets(["", "+24V", "+24V_M", "+5P", "+5V_L", "3V3", "GND_P", "GND_L", "KH", "RELE", "CURR",
          "IN1_LR", "IN2_LR", "SDA_LR", "SCL_LR"] + UNNAMED + NC)

# ---- посадочные места -------------------------------------------------------------------------------
idc_2x06("D"); jst_xh(5, "L"); jst_xh(4, "L"); tb_dg301(vertical=True); dip6(); r_axial(vertical=True); c_disc()
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

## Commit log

2026-09-13 Создание структуры проекта electronics/
    Каталоги lib/, boards/, system/, calc/, bom/, docs/, scripts/
    с заглушками .gitkeep; README.md с описанием структуры, инструментов
    и схемы ревизий; .gitignore под KiCad.
2026-09-13 Добавлен CLAUDE.md с правилами работы в репозитории
    Договорённости по коммитам, структуре KiCad-проектов, библиотекам,
    ревизиям и границам с другими подпроектами.
2026-09-15 Создана база компонентов bom/Component_Base.xlsx — единый источник по электронике
    - bom/Component_Base.xlsx — база компонентов и модулей: листы «Компоненты»
    (53 позиции с узлом, статусом решения, стороной развязки, ценой и пометками
    «Аккуратно!»), «Модули», «Отклонено», «Сводка», «Справочники»; состояние
    на 15.09. Версия базы — история Git, в имени файла не пишется.
    - bom/csv/ — экспорт листов в CSV для просмот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
    [Component_Base.xlsx, Components.csv, Lists.csv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]
2026-09-16 Разделение на платы CH/MC/PS/LR/GR, узел питания завершён, правила генерации KiCad 10
    - docs/board-partition.md — обоснование разделения электроники на платы:
    CH (канал привода, 4 + 1 зап.), MC (главная), PS (питание), LR (панель ЛР),
    GR (схват); состав, связи между платами, порядок проектирования;
    распределительная плата платформы (PD) отклонена.
    - README.md: таблица плат заполнена; версия KiCad — 10.0.
    - База компонентов: ко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
    [Component_Base.xlsx, Components.csv, Lists.csv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]
2026-09-19 Схемы Э3 и платы PS, MC; генераторы KiCad и библиотека manipulator
    - boards/PS, boards/MC: схемы в стиле кафедры (разъёмы таблицами, обозначения X,
    минимум стрелок), платы под нормы Резонита, .kicad_pro с классами цепей
    - scripts: sch_common/pcb_common (общие модули, трассировщик Router),
    gen_<КОД>_sch/pcb, проверки check_sch, check_pcb, check_sch_pcb, preview_sch
    - lib: символы manipulator.kicad_sym, footprint'ы manipulator.pretty,
    рамки worksheets, шрифт GOST 2.304
    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
    [Component_Base.xlsx, Components.csv, MC.kicad_pcb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]
2026-10-04 Библиотека символов переведена в формат KiCad 10
    lib/symbols/manipulator.kicad_sym пересохранена в формате 20251024 (generator_version 10.0):
    убраны пустые (pin_names), шрифт выводов без face/italic, числа округлены как у KiCad.
    УГО оптронов по ГОСТ 2.730 (капсула): КР293КП2Б — контакт по 2.755, 6N137 — усилитель
    по 2.759; позиционное обозначение U вместо VU. Дуги в preview_sch.py — по трём точкам.
    [PS.kicad_pcb, PS.kicad_sch]
2026-10-04 Схемы Э3: платы CH и LR, правки PS и MC
    CH: схема канала привода (gen_CH_sch.py), оптроны в капсулах ГОСТ 2.730, X1 — вилка _D.
    LR: схема панели (gen_LR_sch.py). PS: кнопка питания одним разъёмом X2 (B4B-XH-A:
    контакт C–NO и индикатор 24 В), X12 убран, VD1 в линию с X1.1, примечания 5–6.
    MC: узел U1 (КР293) под новое УГО, R5/R9, шина KH до R5. Сетка 1,27 у PS и LR.
    check_sch.py: блоки «сетка 1,27» и «посадочные места».
    [CH.kicad_sch, LR.kicad_sch, MC.kicad_sch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]
2026-10-04 Библиотека посадочных мест: исправлены зеркальные варианты, добавлены 3D-модели
    _L (JST XH/VH) и IDC 2x06 были зеркальными: у реальных разъёмов при такой ориентации
    нумерация шла в обратную сторону (на MC X2/X5 — переполюсовка питания). Теперь только
    повороты: у _L вывод 1 снизу, у IDC при ключе вверху вывод 1 справа; добавлен вариант _D.
    FP.set_model(): 16 STEP из библиотеки KiCad в lib/3dmodels, привязаны к 19 местам,
    по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
    [gen_footprints.py, pcb_common.py]
2026-10-04 Плата CH: расстановка узлами, трассировка «plane», проверки DFM
    gen_CH_pcb.py: реле K4…K1 на границе развязки, строки «резистор — оптрон — подтяжка»,
    DA1/DA2/X4/X5 справа, делитель CURR на острове; 0 непроложенных цепей, 45 переходов
    (предварительная разработка: нет чертежей корпуса, NRP-02 и модулей). check_pcb.py:
    высота компонентов и компоненты под модулями. gen_LR_pcb.py — генератор платы LR.
    Платы PS и MC подлежат пер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
    [CH.kicad_pcb, LR.kicad_pcb]
2026-10-04 CLAUDE.md: план проверки проекта, 3D-модели, варианты ориентации; журнал ERC/DRC и шпаргалка
    План проверки перед каждой выдачей схемы/платы, формат библиотеки KiCad 10, правило
    «варианты ориентации — только повороты», gen_footprints.py. Журнал проверок ERC/DRC,
    шпаргалка по развязкам, согласованию линий и паразитным ёмкостям, чек-лист DFM;
    calc/ — разбиение на платы и footprint'ы PS (перенесены из docs/). .gitignore: книга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
2026-10-05 Платы PS, MC, CH, LR: расстановка, трассировка, 3D-модели посадочных мест
    PS:
    - разведена по расстановке из файла: +24V_IN 6 мм (участок у K1 — 4 мм),
    шина +24V 6 мм с отводами 3 мм, +5P 2 мм, остров U2 1,5 мм;
    заливка GND_P на B.Cu, вырез заливки под островом, вырезы ⌀8 у крепежа
    - классы цепей в PS.kicad_pro: Default, Power5, Power24, Island
    - U1: посадочное место под модуль XL4015E 54 × 24 × 15 на штырях
    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
    [CH.kicad_pcb, CH.kicad_sch, Component_Base.xlsx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]
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2026-10-07 Документы плат PS, MC, CH, LR; обозначения по схеме кафедры, наименования плат
    - Документы плат PS, MC, CH, LR: перечень элементов, схема Э3, чертёж
    печатной платы, сборочный чертёж, спецификация (docs/<КОД>/)
    - .gitignore: выпущенные документы docs/<КОД>/*.pdf хранятся в истории
    - 3D-модели плат boards/<КОД>/<КОД>.step — исходные данные для проекций СБ
    - Обозначения СМ7.02.ПП.ДД.00: ПЭ3, Э3, СБ — .00.00, плата печатная — .01.00,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
    [CH.kicad_pcb, CH.kicad_sch, CH.step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]
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
